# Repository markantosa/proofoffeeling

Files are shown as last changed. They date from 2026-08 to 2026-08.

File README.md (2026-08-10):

# Proof of Feeling

**Affective Core AC-7** — a speculative mechatronic artefact: an artificial
robotic heart that makes a humanoid AI's internal state visible through
pulse, motion, and light.

<p align="center">
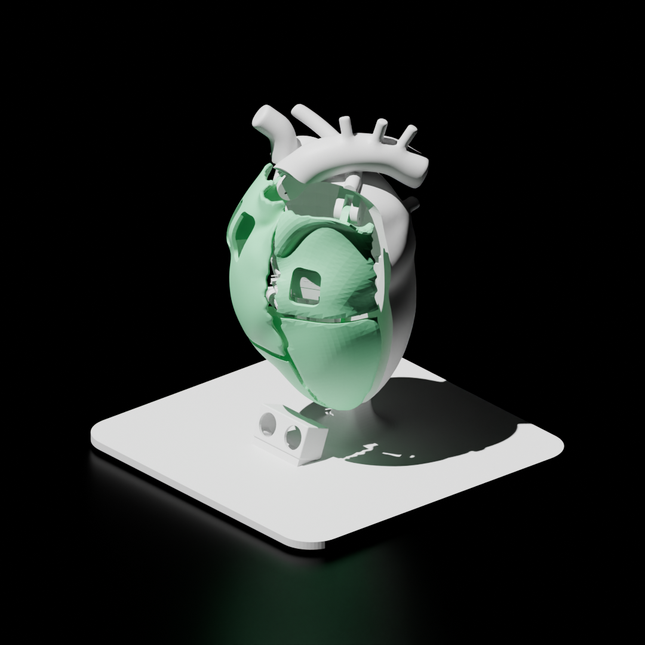
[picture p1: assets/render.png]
Proof of Feeling — rendered artificial heart with exposed PCB, mounted on its display stand
  
  <br><sub>Render made in Blender.</sub>
</p>

<p align="center">
  <a href="https://youtu.be/jkcCoCJa7ys">
    Proof of Feeling — short demo video (YouTube)
  </a>
  <br><sub>▶ Short demo — <a href="https://youtu.be/jkcCoCJa7ys">watch on YouTube</a></sub>
</p>

See [`docs/design-reference.md`](docs/design-reference.md) for the full
project concept and design brief.

## Repository Layout

```
.
├── docs/               Project-wide documentation
│   ├── design-reference.md          Project context/story + physical prototype
│   └── pcb-design-reference.md      KiCad 10 PCB design reference
├── firmware/           ESP32-C6-Supermini embedded firmware
│   ├── src/             Servo sweep, LED chase, proximity speed, eye animation, BLE telemetry
│   └── include/          Pin assignments, tunables, BLE UUIDs
├── dashboard/          BLE debug dashboard — ASCII face/sonar/heartbeat, Web Bluetooth (Chrome/Edge only)
├── electronics/        KiCad PCB project (single-layer milled board)
└── mechanical/         3D models — printable STL/3MF tracked via Git LFS; source .blend files not included yet
```

## Hardware Summary

* ESP32-C6-Supermini
* 2x SG92R micro servos, 5V (continuous 0–180° sweep, mirrored) — chosen over MG995 for size
* HC-SR04 ultrasonic sensor (proximity → continuous speed control)
* 1x momentary button, wired but currently unused by firmware
* 8x auxiliary LEDs, top-to-bottom chase ("pulse point" glow array)
* I2C OLED (SSD1306-class), 4-pin header — always-on blinking eye
* BLE telemetry (built-in radio) — feeds the debug dashboard, see below
* Custom single-layer milled PCB (KiCad, `electronics/`)
* Powered via 5V DC barrel plug

## Tools

* 3D modelling — Blender
* PCB design — KiCad
* Firmware — written with the aid of Claude

## Credits

* Heart geometry developed from [Realistic Human Heart](https://sketchfab.com/3d-models/realistic-human-heart-3f8072336ce94d18b3d0d055a1ece089) (Sketchfab)

<table>
  <tr>
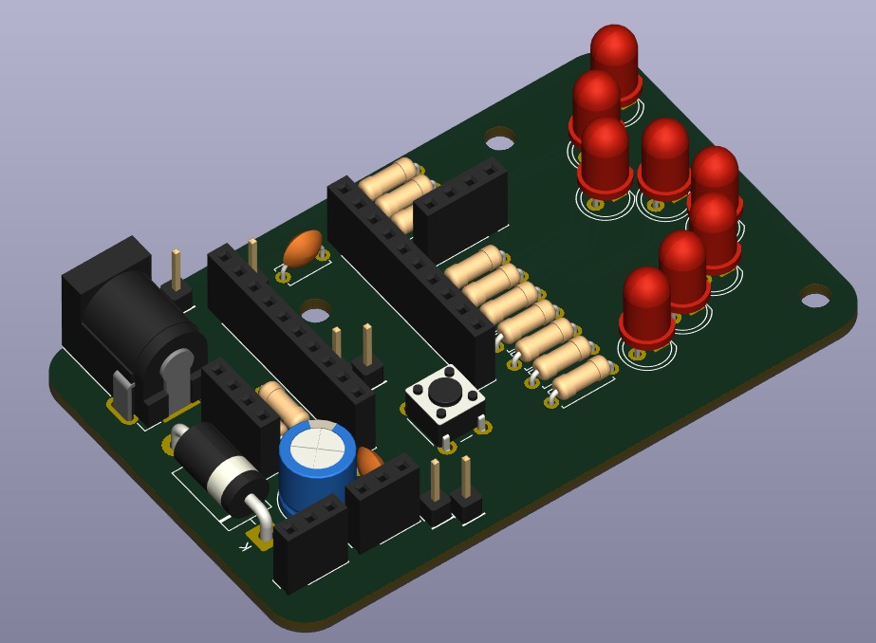
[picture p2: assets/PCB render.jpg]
3D render of the populated AC-7 main board
    <td align="center"><br><sub>Populated board render</sub></td>
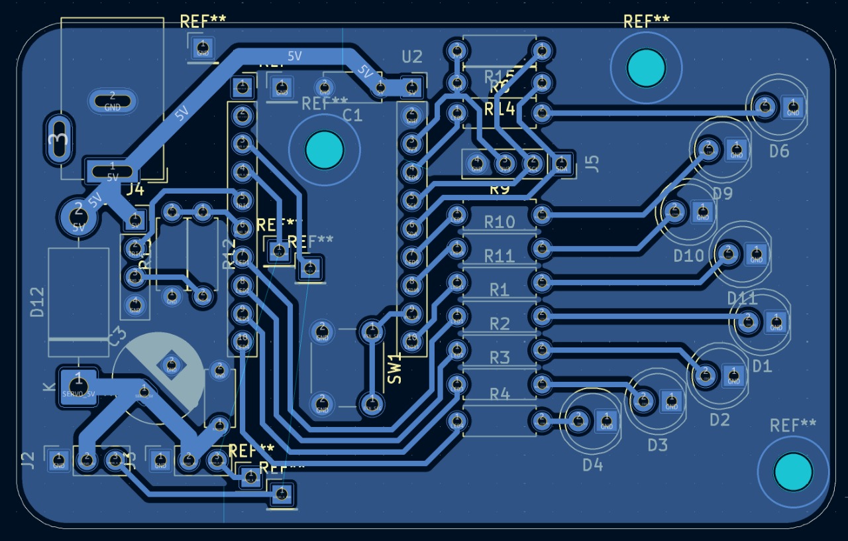
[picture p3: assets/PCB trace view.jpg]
AC-7 PCB routing — single-layer milled board, B.Cu traces
    <td align="center"><br><sub>B.Cu routing</sub></td>
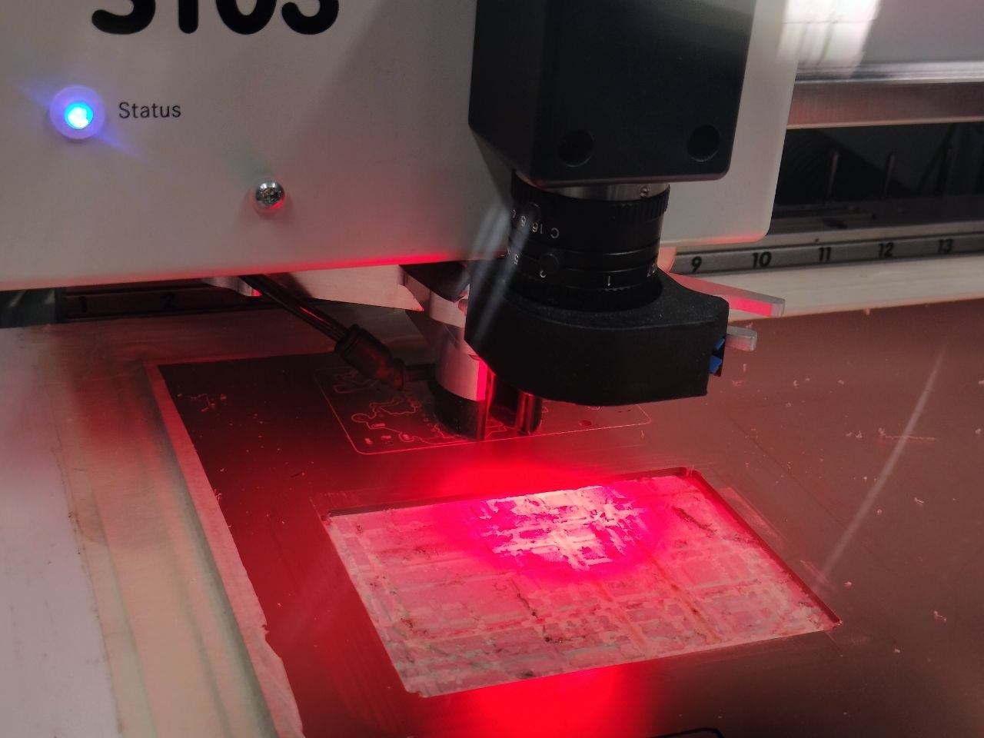
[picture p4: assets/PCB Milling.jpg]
AC-7 board mid-fabrication on a desktop CNC isolation mill
    <td align="center"><br><sub>Desktop CNC isolation milling</sub></td>
  </tr>
</table>

## Build

<table>
  <tr>
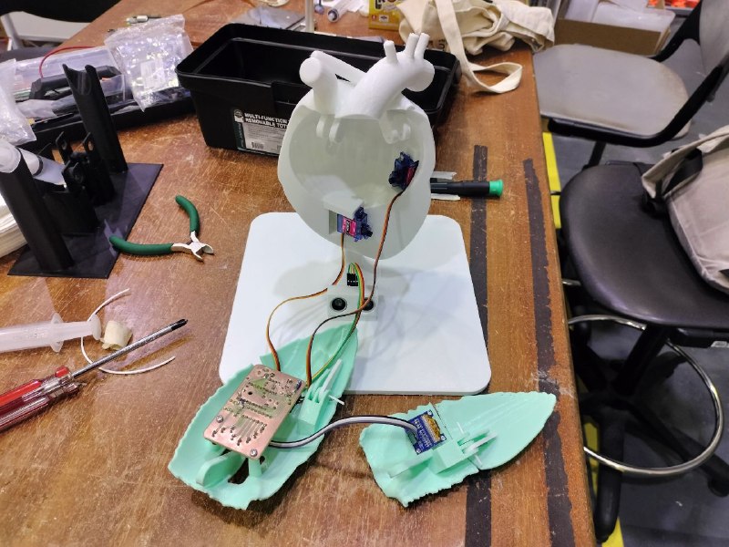
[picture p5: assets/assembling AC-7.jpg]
AC-7 mid-assembly — 3D-printed shell, PCB, and wiring on the workbench
    <td align="center"><br><sub>Assembly</sub></td>
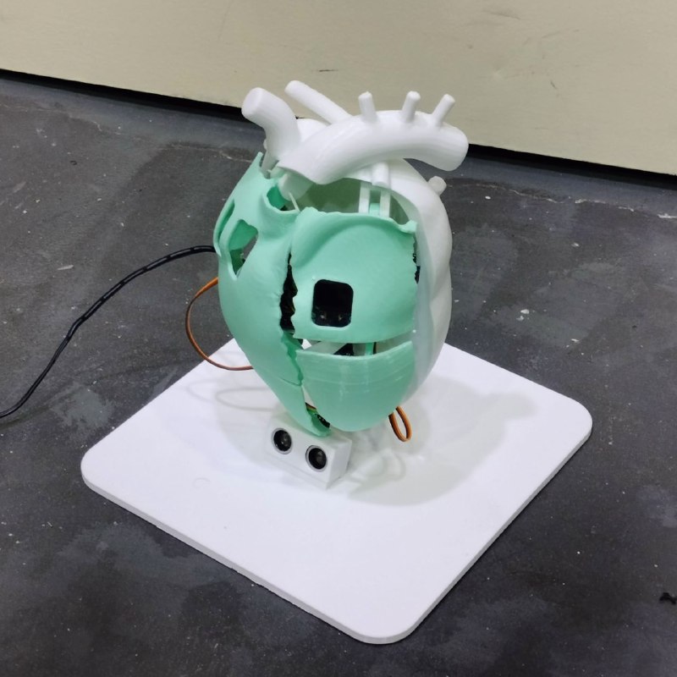
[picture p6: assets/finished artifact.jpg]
Finished AC-7 artefact — assembled artificial heart on its display stand
    <td align="center"><br><sub>Finished artefact</sub></td>
  </tr>
</table>

## Getting Started

* Project context, story, and what a viewer experiences: [`docs/design-reference.md`](docs/design-reference.md)
* Firmware build/flash instructions: [`firmware/README.md`](firmware/README.md)
* PCB design reference: [`docs/pcb-design-reference.md`](docs/pcb-design-reference.md)
* KiCad project: [`electronics/EPD 3D G6.kicad_pro`](electronics/EPD%203D%20G6.kicad_pro)
* BLE debug dashboard: [`dashboard/index.html`](dashboard/index.html) — open directly in Chrome or Edge (desktop/Android; Web Bluetooth isn't supported in Firefox/Safari), click **Connect**, pick "AC-7"

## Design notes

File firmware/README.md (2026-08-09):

# Affective Core AC-7 — Firmware

Embedded firmware and electronics documentation for **Proof of Feeling**, a
speculative mechatronic artefact. The Affective Core is an artificial
robotic heart that makes a humanoid AI's internal state visible through
pulse, motion, and light.

See [`../docs/design-reference.md`](../docs/design-reference.md) for the
full project concept and design brief.

## Hardware

* ESP32-C6-Supermini
* 2x SG92R micro servos, 5V (continuous 0–180° sweep, mirrored) — chosen over MG995 for size
* HC-SR04 ultrasonic sensor (proximity → continuous speed control)
* 5V DC barrel plug power input
* 1x momentary button — wired on the board (BTN_SIG/SW1), not read by
  the current firmware revision
* 8x auxiliary LEDs, chase top-to-bottom ("pulse point" glow array; 4
  PWM-faded, 4 on/off — see PCB doc for the LEDC channel budget)
* I2C OLED (SSD1306-class), 4-pin header — always-on eye animation,
  blinks at random intervals
* BLE telemetry (built-in radio, no extra hardware) — broadcasts
  distance + speed multiplier for the debug dashboard, see below
* Custom single-layer milled PCB — see
  [`../docs/pcb-design-reference.md`](../docs/pcb-design-reference.md)

## Repository Layout

This folder holds only the firmware; project-wide docs live in
[`../docs/`](../docs/) at the repo root, and the BLE debug dashboard
lives in [`../dashboard/`](../dashboard/).

```
.
├── platformio.ini          PlatformIO project config
├── include/
│   ├── config.h              Pin assignments and tunables
│   └── ble_telemetry.h       BLE service/characteristic declarations
└── src/
    ├── main.cpp               Servo sweep, LED chase, proximity speed, eye animation
    └── ble_telemetry.cpp      BLE GATT server — notifies distance + speed to the dashboard
```

## Build & Flash

Requires [PlatformIO](https://platformio.org/).

```
pio run              # build
pio run -t upload    # flash to ESP32-C6-Supermini
pio device monitor    # serial monitor, 115200 baud
```

## Behaviour (v3.0)

Continuous, proximity-driven — no discrete interaction-mode state
machine in this revision (an earlier v2.0 draft had one; it's gone):

| Element | Behaviour |
|---|---|
| Aux LEDs | Chase top-to-bottom in a wrapping pulse, continuously |
| Servos | Sweep 0°→180°→0° continuously, mirrored between the two |
| Speed | Both the LED chase and servo sweep speed up continuously as an object gets closer to the HC-SR04 — no discrete thresholds |
| OLED | Always displays an eye; blinks at random intervals, independent of the above |
| BLE | Notifies distance + speed multiplier (~10Hz) whenever a client is connected; harmless if nothing's listening |

See [`../docs/design-reference.md`](../docs/design-reference.md) §2 for
what this looks like from a viewer's side. The button (`BTN_SIG`) is
wired but currently unused — a candidate for a future interaction if one
gets designed.

## BLE Debug Dashboard

The firmware advertises as **AC-7** and exposes one GATT service (see
`include/ble_telemetry.h` for the UUIDs) that notifies an 8-byte struct
— `distanceCm` + `speedMultiplier` — at ~10Hz whenever a client is
connected. [`../dashboard/index.html`](../dashboard/index.html) is a
self-contained Web Bluetooth client for it: open it in Chrome or Edge
(desktop or Android — Web Bluetooth isn't supported in Firefox/Safari),
click **Connect**, and it renders:

* an ASCII face (sleeping / happy / stressed, thresholded on distance)
* an ASCII sonar sweep, pinging when something's in range
* a heartbeat thump + visual pulse, tempo-matched (not phase-locked) to
  the servo/LED speed

It's a debugging/demo tool, not part of the physical artefact — nothing
in `main.cpp`'s actual behaviour depends on whether a dashboard is
connected.

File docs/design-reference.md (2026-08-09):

# PROOF OF FEELING — DESIGN REFERENCE

**Affective Core AC-7** · Speculative Design / Mechatronic Artefact
Author: Vincent Santosa

---

## 1. Project Context & Story

*Proof of Feeling* is a speculative artefact from a near-future in which
humanoid robots have become convincing enough at simulating emotion that
human trust in them collapses. Regulators respond the way institutions
usually respond to a trust crisis: not by earning trust, but by
mandating proof of it. Every advanced humanoid must now contain an
**Affective Core** — a commercially manufactured robotic heart, sold
under the brand **AC-7** by *Companion Systems Inc.*, that makes a
robot's internal state externally visible through pulse, motion, and
light.

The heart does not sustain the robot. It sustains the *human's belief*
in the robot. That distinction is the entire design brief: this is not a
life-support organ, it's a trust interface wearing the shape of one —
performative rather than biological, engineered to be watched rather
than to function.

**Why this framing matters:** the project's actual subject isn't
robotics — it's what happens when trust is demanded on command instead
of earned. Manufactured proof of an inner state is not the same thing as
the inner state itself; it's a performance authored by whoever controls
the evidence. In the world of the AC-7, that's Companion Systems Inc. —
they design the pulse curves, choose the light behaviour, and program
every interaction mode in advance. The robot never gets to generate its
own evidence of feeling; the corporation does it on the robot's behalf,
the same way a regulator's compliance certificate stands in for the
thing it certifies. The heart is affirmative *within* the fiction (a
branded, reassuring, compliant product) while functioning as *critical*
design when offered to a viewer — it deliberately declines to answer
whether visible emotion equals genuine emotion, or who actually benefits
once a feeling becomes measurable and sellable.

This is also where the project is personal rather than purely
speculative. It's shaped by a Javanese sense that humility and quiet
consistency earn trust, while insistence on being seen and believed
usually signals the opposite — a relationship (or a system) that doesn't
trust itself enough to go unwatched. The AC-7 inverts that: it rewards
spectacle over restraint, and treats legibility as though it were the
same thing as trustworthiness. The project doesn't resolve that tension.
It's built to make a viewer sit inside it.

### The critical question

Not "can robots have feelings?" but:

**What happens when emotion becomes a manufactured interface?**

— and, closer to the surface: can empathy be engineered? Can trust be
designed? Is visible suffering required for moral consideration? Does
emotional transparency create understanding, or control? Who benefits
when emotion becomes measurable?

---

## 2. The User Side — Experiencing the Physical Prototype

The prototype is displayed as a **removed organ undergoing inspection**,
not a sculpture — the audience should feel they're looking at a real
industrial artefact, complete with product labels, serial numbers, and
inspection warnings ("Trust calibration required every 500 operating
hours."), sitting in a display cradle labelled `AFFECTIVE CORE · MODEL
AC-7 · PROPERTY OF COMPANION SYSTEMS INC.`

There is no button to press, no explicit "start" — the object is always
performing, the same way the fiction insists a real Affective Core would
be. What a viewer actually experiences:

* **It's always alive.** Two servo-driven anatomical structures move
  continuously — a slow, sweeping contraction/twist, mirrored between
  the two, so the object never looks static or off.
* **A pulse of light chases through the shell**, top to bottom, through
  a row of exposed "pulse point" LEDs behind the shell's translucent
  cutouts — read as bioelectric or vein-like activity rather than a
  simple blink.
* **It notices you.** An ultrasonic sensor detects when a viewer leans
  in. As they get closer, both the light pulse and the servo motion
  speed up — continuously, not as a discrete jump — so the object reads
  as *reacting to attention*, the same way a heart rate rises under
  scrutiny. Stepping back lets it slow back down.
* **It has an eye.** A small embedded screen shows a single eye that
  blinks at irregular, unscripted-feeling intervals — the one part of
  the object that behaves less like an instrument and more like it's
  looking back.
* **It carries the evidence of inspection**, not concealment: exposed
  copper traces styled after blood vessels and neural pathways, visible
  test points, fasteners, and calibration tags — synthetic and organic
  and corporate registers layered on top of each other on purpose.

The intended effect isn't "this looks alive" — it's closer to "this
looks like it was *designed to convince me* it's alive," and leaving
that gap visible is the point. A viewer who leans in and watches the
object visibly quicken in response is, in that moment, doing exactly
what the fiction's regulators designed the object for: deciding whether
to trust a machine by watching it perform. The project succeeds if that
prompts the discomfort of "would I actually trust something more because
it looks vulnerable to me?" — and fails if the only questions it
provokes are about the engineering (*what servo is that, does the
sensor work*) rather than the premise.

---

## Appendix: Physical Envelope

Target: 300mm × 250mm × 200mm · Maximum: 400mm × 400mm × 400mm (course
compliance).

For hardware specifics — servo/sensor/LED/display wiring, GPIO
assignments, firmware behaviour — see
[`pcb-design-reference.md`](pcb-design-reference.md) and
[`../firmware/README.md`](../firmware/README.md).

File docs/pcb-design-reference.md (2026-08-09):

# AFFECTIVE CORE AC-7 — PCB DESIGN REFERENCE

## Single-Layer Milled Board — KiCad 10

This revision matches the finalized schematic exactly (2 header rows for
the Supermini, 8 populated aux LEDs, I2C OLED header). Reference
designators follow the schematic's own numbering — see §5 for the full
scheme, in particular: **`D1`–`D11` are LEDs numbered to match their LED
net** (`D1`=`LED1` … `D11`=`LED11`), while **`D12` is the reverse-polarity
protection diode** — this is the opposite convention from earlier drafts
of this doc, so don't cross-reference old revisions.

---

# 1. BOARD OVERVIEW

Fabrication method: desktop CNC isolation milling (single-sided, copper on
bottom only — B.Cu). No vias, no plated through-holes, no top-side routing.
All components are through-hole (THT) so every connection can be made by a
hand-solderable pad reached from one side.

Because this is a single copper layer, every net that would otherwise need
to cross another net must either:

1. Route around it (preferred — and consistent with the "vein / neural
   pathway" decorative trace language in the main design doc), or
2. Jump it with a 0Ω resistor / bare wire link soldered on the top
   (component) side, treated in KiCad as a 2-pin "jumper" footprint.

Budget for 6–10 such jumpers on this board — the ESP32-C6-Supermini sits in
the middle of the layout with pins on both long edges, and the aux LED
array spans both rows, which forces several nets from one side to reach
components/headers on the other.

Board outline target: fits inside the heart shell cradle, roughly
70mm x 50mm. Confirm against the 3D-printed shell's internal mounting boss
positions before finalizing Edge.Cuts.

**Note on BLE**: the firmware broadcasts telemetry over Bluetooth LE (for
the debug dashboard — see `firmware/README.md`) using the Supermini
module's onboard radio/antenna. This needs no PCB component, footprint,
or net of its own — nothing on this board changes because of it.

---

# 2. KICAD 10 PROJECT SETUP

## 2.1 New Project

* File → New Project → "AC7_MainBoard"
* Symbol library: use default KiCad symbol libraries (Device, Connector,
  Switch) — no custom symbols required, see §5.
* Footprint library: default KiCad footprints (Resistor_THT, LED_THT,
  Connector_PinHeader_2.54mm, Connector_PinSocket_2.54mm,
  Button_Switch_THT) — no custom footprint needed, see §5.1.

## 2.2 Board Setup → Physical Stackup

* File → Board Setup → Board Editor Layers
* Untick every layer except: **F.Cu is NOT used** — untick it too.
  Keep only **B.Cu** enabled as the sole copper layer, plus Edge.Cuts,
  F.Silkscreen (for your own reference only — silkscreen will not be
  printed by the mill, but keeping it helps you read the layout on screen),
  and F.Fab/F.Courtyard if you want assembly reference.
* Rationale: all components are placed on the top (F) side and soldered
  through to pads that are milled on the bottom (B.Cu) side. Routing must
  therefore happen entirely on B.Cu.

## 2.3 Design Rules (Board Setup → Design Rules → Constraints)

Tuned for a typical 0.8–1.0mm end-mill / 0.1mm–0.2mm V-bit isolation job:

| Rule | Value |
|---|---|
| Minimum track width | 0.4mm (0.5mm preferred for power/servo nets) |
| Minimum clearance | 0.4mm |
| Minimum via | N/A — vias disabled, single layer |
| Minimum hole size | 0.8mm (drill), pad ≥ 1.7mm OD |
| Copper-to-edge clearance | 0.5mm |

Power nets (`+5V`, `SERVO_5V`, `GND`) should be widened to 0.8–1.0mm
manually where routing space allows. Both servos are SG92R micro servos
and draw stall currents in the ~650–750mA range each (~1.5A combined
worst case) — well within what a 0.4mm trace could handle at this
length, but the wider power-net width is cheap insurance and keeps
`SERVO_5V` consistent with the `+5V`/`GND` nets it shares a net class
with.

## 2.4 Net Classes

Create two net classes under Board Setup → Design Rules → Net Classes:

* **Default** — 0.4mm track / 0.4mm clearance — signal, sensor, LED, I2C,
  and `+3V3` nets.
* **Power** — 0.8mm track / 0.4mm clearance — assign nets `+5V`, `GND`,
  `SERVO_5V`.

## 2.5 Plotting for the Mill

File → Plot, or File → Fabrication Outputs:

* Export **B.Cu** and **Edge.Cuts** as Gerber (or SVG/DXF if your CAM chain
  — e.g. FlatCAM, pcb2gcode, Candle/GRBL — prefers vector formats).
* Export drill file via File → Fabrication Outputs → Drill Files
  (Excellon, one drill file, PTH+NPTH merged since nothing is plated).
* Because copper is on B.Cu only, **mirror the export** if your CAM
  workflow assumes you're milling the layer you're looking at from the top
  — check a test cut on scrap copper-clad before committing the real board.

---

# 3. POWER ARCHITECTURE

* **Input**: 5V DC via a 5V barrel plug (J1), external supply rated at
  least 5V/2A to cover two SG92R servos' combined stall current
  (~1.5A worst case) plus the Supermini and LED array headroom.
* **Two separate 5V nets** — this is the one subtlety worth calling out
  clearly, since it's easy to assume everything downstream of J1 is
  protected the same way:
  * **`+5V`** — raw, straight off J1, *before* the protection diode.
    Feeds the Supermini's own 5V/VIN pin (`U2` pin 1) and the HC-SR04
    (`J4` pin 1) directly.
  * **`SERVO_5V`** — *after* D12 (the reverse-polarity diode), feeds only
    the two servo headers (J2/J3). Only the servo rail is diode-protected
    in this design; the MCU and ultrasonic sensor are not. If reverse
    polarity protection for the whole board matters to you, that's worth
    revisiting, but as drawn, only the high-current/most-exposed servo
    path gets it.
* **ESP32-C6 logic**: 3.3V, generated on-module by the Supermini's onboard
  regulator. The one net distributed off that regulator on this PCB is
  **`+3V3`** (from `U2` pin 3), which powers the I2C OLED (J5) and its
  pull-up resistors (R14/R15). An SSD1306-class OLED draws well under the
  regulator's spare headroom (typically <20mA), so no separate 3.3V
  regulation is needed.
* **HC-SR04**: runs on raw `+5V`. Its ECHO output swings to 5V and MUST be
  divided down before reaching the C6's 3.3V-only GPIO (R12/R13 divider,
  see §4). TRIG is driven by a 3.3V GPIO, which the HC-SR04 reliably reads
  as logic HIGH — no level shifting needed on TRIG.
* **Reverse-polarity protection**: D12, a Schottky diode (e.g. SS24,
  rated ≥2A — comfortable margin over the two SG92R servos' ~1.5A
  combined stall current) in series between `+5V` and `SERVO_5V`. Costs
  ~0.3V drop on the servo rail only.

---

# 4. NET LIST

| Net name | Description | Connects |
|---|---|---|
| `+5V` | Raw 5V input rail (pre-diode) | J1.1, D12 anode, U2.1 (Supermini VIN), J4.1 (HC-SR04 VCC), C1 |
| `SERVO_5V` | Post-diode 5V, servos only | D12 cathode, J2.2, J3.2, C2, C3 |
| `GND` | Common ground | J1.2, U2.2, J2.1, J3.1, J4.4, SW1 (leg 2), J5.4, R13 (divider low side), all LED cathodes (D1–D11) |
| `SERVO_A_PWM`  | Servo A signal | U1.3 → J2.3 |
| `SERVO_B_PWM`  | Servo B signal | U1.4 → J3.3 |
| `TRIG` | Ultrasonic trigger | U1.5 → J4.2 |
| `ECHO_5V` | Raw 5V echo output from HC-SR04 | J4.3 → R12 |
| `ECHO_3V3` | Divided echo signal into MCU | R12/R13 junction → U1.6 |
| `BTN_SIG` | Button input | U2.9 → SW1 (leg 1) |
| `LED1`…`LED4`  | Aux LEDs — PWM-faded (4 of 6 free LEDC channels; servos use the other 2) | U1.7/8/9/10 → R1…R4 → D1…D4 anode |
| `LED6` | Aux LED — on/off | U2.4 → R6 → D6 anode |
| `LED9` | Aux LED — on/off | U2.7 → R9 → D9 anode |
| `LED10` | Aux LED — on/off | U2.8 → R10 → D10 anode |
| `LED11` | Aux LED — on/off. Shares GP8 with the onboard WS2812 DIN (see §5.2) | U2.10 → R11 → D11 anode |
| `+3V3` | 3.3V, tapped from the Supermini's onboard regulator | U2.3 → J5.3, R14/R15 pull-ups |
| `I2C_SDA` | I2C data, OLED | U2.6 → J5.1, pull-up to `+3V3` |
| `I2C_SCL` | I2C clock, OLED | U2.5 → J5.2, pull-up to `+3V3` |

**LED numbering has gaps by design** — `LED5`, `LED7`, `LED8` don't exist
on this board. `LED5` (GP12) was dropped entirely; `LED7`/`LED8` (GP19/
GP18) were reassigned to `I2C_SCL`/`I2C_SDA` instead. This is expected,
not a missing-component error — see §5.2 for the full pin-by-pin
accounting.

**LED physical position, top → bottom on the shell** (this is the order
the firmware chases through — see `include/config.h` `PIN_LED_AUX[]`):

```
LED6 → LED9 → LED10 → LED11 → LED1 → LED2 → LED3 → LED4
```

| Position (top→bottom) | LED | GPIO | Resistor | Diode | Drive |
|---|---|---|---|---|---|
| 1 | LED6  | 20 | R6 | D6 | on/off |
| 2 | LED9  | 15 | R9 | D9 | on/off |
| 3 | LED10 | 14 | R10 | D10 | on/off |
| 4 | LED11 | 8 (also WS2812 DIN) | R11 | D11 | on/off |
| 5 | LED1  | 4 | R1 | D1 | PWM (fade) |
| 6 | LED2  | 5 | R2 | D2 | PWM (fade) |
| 7 | LED3  | 6 | R3 | D3 | PWM (fade) |
| 8 | LED4  | 7 | R4 | D4 | PWM (fade) |

⚠️ **LEDC channel budget**: the ESP32-C6 has 6 total LEDC PWM channels.
The 2 servos consume 2, leaving 4 free — that's why only LED1–LED4 fade;
the rest are driven as plain digitalWrite on/off in firmware
(`writeAuxLed()` in `main.cpp`), not PWM-capable, so no LEDC channel is
needed for them. Physically, the 4 fading LEDs are the second half of the
chase (positions 5–8), not the first — the pulse animation still reads
fine either way since it's a continuous glow sweep, not a fixed brightness
step.

---

# 5. REFERENCE DESIGNATORS, SYMBOLS & FOOTPRINTS

| Ref | Part | KiCad Symbol (library:name) | KiCad Footprint | Notes |
|-----|---|---|---|---|
| U1  | ESP32-C6-Supermini, left pin row (plugs into sockets — see §5.1) | `Connector_Generic:Conn_01x10` — no stock symbol matches the Supermini's specific pinout, label each pin manually | `Connector_PinSocket_2.54mm:PinSocket_1x10_P2.54mm_Vertical` — stock footprint, no custom footprint needed | Only 10 of the row's 12 physical pins are used (pins 1–2 are TX/RX, unconnected); pins 11–12 (GP23/GP22) aren't wired to anything |
| U2  | ESP32-C6-Supermini, right pin row (plugs into sockets — see §5.1) | `Connector_Generic:Conn_01x10` — same caveat as U1 | `Connector_PinSocket_2.54mm:PinSocket_1x10_P2.54mm_Vertical` | Only 10 of the row's 14 physical pins are used — pin 1 (BAT) and pins 12–14 (GP12/GP13/GP21) aren't wired to anything. See §5.2 for the full physical-to-schematic pin mapping |
| J1  | Power input, 5V DC barrel plug | `Connector:Barrel_Jack` | `Connector_BarrelJack:BarrelJack_Horizontal` | Rate for ≥3A; match plug OD/ID to the chosen 5V supply |
| D12 | Schottky diode, reverse-polarity protection (`SERVO_5V` only) | `Diode:D_Schottky` (generic Schottky symbol — set Value field to `SS24`; there is no part-specific `SS24` symbol in the stock library) | `Diode_THT:D_DO-201AD_P15.24mm_Horizontal` | Rated ≥2A — comfortable margin over SG92R stall current |
| J2  | Servo A header (3-pin: GND/SERVO_5V/PWM) | `Connector_Generic:Conn_01x03` | `Connector_PinHeader_2.54mm:PinHeader_1x03_P2.54mm_Vertical` | Pin order per schematic: GND, SERVO_5V, SERVO_A_PWM — confirm against your SG92R plug wire colors before crimping |
| J3  | Servo B header (3-pin) | `Connector_Generic:Conn_01x03` | `Connector_PinHeader_2.54mm:PinHeader_1x03_P2.54mm_Vertical` | Same pin order as J2 |
| J4  | HC-SR04 header (4-pin: 5V/TRIG/ECHO_5V/GND) | `Connector_Generic:Conn_01x04` | `Connector_PinHeader_2.54mm:PinHeader_1x04_P2.54mm_Vertical` | Order to match sensor module silkscreen |
| J5  | I2C OLED header (4-pin: SDA/SCL/3V3/GND) | `Connector_Generic:Conn_01x04` | `Connector_PinHeader_2.54mm:PinHeader_1x04_P2.54mm_Vertical` | Pin order is SDA, SCL, 3V3, GND per schematic — this does **not** match every OLED breakout's silkscreen order, double-check before wiring |
| SW1 | Momentary tactile button | `Switch:SW_Push` | `Button_Switch_THT:SW_PUSH_6mm` | Leg 1 → `BTN_SIG`, leg 2 → `GND`. Wired on the board but not read by the current firmware revision |
| D1–D4, D6, D9–D11 | Aux LEDs (8x populated, 3mm or 5mm THT) — designator matches LED net number, **not** sequential (D5/D7/D8 don't exist) | `Device:LED` | `LED_THT:LED_D5.0mm` (or `LED_D3.0mm`) | Route to physical positions on the shell per the top→bottom chase order in §4 |
| R1–R4, R6, R9–R11 | LED current-limit resistors (330Ω for 5mm red/amber LEDs at 3.3V/5V logic; recalc per LED Vf/If) — same gapped numbering as the diodes | `Device:R` | `Resistor_THT:R_Axial_DIN0207_L6.3mm_D2.5mm_P10.16mm_Horizontal` | One per LED, in series with GPIO |
| R12 | Echo divider, top (5V side) | `Device:R` — 1kΩ | `Resistor_THT:R_Axial_DIN0207_L6.3mm_D2.5mm_P10.16mm_Horizontal` | R12/R13 form a 2:1 divider: 5V × (R13/(R12+R13)) ≈ 3.3V |
| R13 | Echo divider, bottom (GND side) | `Device:R` — 2kΩ | `Resistor_THT:R_Axial_DIN0207_L6.3mm_D2.5mm_P10.16mm_Horizontal` | Junction of R12/R13 → `ECHO_3V3` → U1.6 |
| R14, R15 | I2C pull-ups — 4.7kΩ, one on SDA one on SCL | `Device:R` | `Resistor_THT:R_Axial_DIN0207_L6.3mm_D2.5mm_P10.16mm_Horizontal` | Omit both if your OLED breakout already has onboard SDA/SCL pull-ups (most SSD1306 modules do — check before populating). **Verify which of R14/R15 lands on SDA vs SCL against your schematic file** — both are 4.7kΩ so a swap has no functional effect, but keep your silkscreen/BOM consistent |
| C1  | Decoupling on `+5V`, near U2 pin 1 (Supermini VIN) | `Device:C` — 100nF | `Capacitor_THT:C_Disc_D3.0mm_W2.5mm_P2.50mm` | |
| C2  | Decoupling on `SERVO_5V`, near J2/J3 | `Device:C` — 100nF | `Capacitor_THT:C_Disc_D3.0mm_W2.5mm_P2.50mm` | |
| C3  | Bulk decoupling on `SERVO_5V`, near J2/J3 | `Device:C_Polarized` — 220–470µF, 16V | `Capacitor_THT:CP_Radial_D8.0mm_P3.50mm` | Damps servo current-draw transients so they don't reset the C6 |

## 5.1 ESP32-C6-Supermini — Socketed Mounting (Header Sockets)

The module plugs into header sockets rather than being soldered or laid out
as a custom module footprint. This means the PCB side only needs two stock
2.54mm pin-socket footprints — no custom `.kicad_mod` required:

* Solder two **female 2.54mm pin header sockets** to the PCB, spaced
  ~17.8mm apart center-to-center (verify against the actual module you
  have; Supermini clones vary between vendors even when visually similar
  — measure before milling).
* The physical header rows are 12 pins (left) and 14 pins (right), but
  this schematic only wires up 10 pins on each side — see §5.2 for
  exactly which physical pins are used vs left unconnected. You can
  either socket only the pins you need, or socket the full row and leave
  the unused pads unpopulated/no-connect — either works.
* PCB footprint: stock `Connector_PinSocket_2.54mm:PinSocket_1x10_P2.54mm_Vertical`
  for the 10 populated positions on each row (or size to the full
  physical row length if you'd rather socket the whole thing).
* Schematic symbol for each row: stock `Connector_Generic:Conn_01x10`
  (U1, U2). There is no ESP32-C6-Supermini symbol in the stock KiCad
  library and none is needed for a socketed connector — just rename each
  pin in the symbol properties/net labels to match the module's actual
  silkscreen, rather than modeling a dedicated MCU symbol.
* The module itself needs no PCB footprint at all — it's a separate,
  removable part that carries its own male header pins and simply plugs
  into the sockets. This is also what makes it swappable if a module is
  damaged during the build.

Before laying out nets to U1/U2, confirm your physical module's actual
pin labels with a multimeter continuity check against its
datasheet/silkscreen — clone boards from different vendors are not
pin-identical.

## 5.2 Pinout Quick Reference

Every physical pin on both header rows, its net on this board (from §4),
and what it's used for. `—` means the pin is present on the module but
not wired to anything on this schematic.

**U1 — left row (physical 12 pins, top → bottom; only pins 1–10 wired)**

| Pin | Module Label | Net | Usage |
|-----|---|---|---|
| 1 | TX | — | Unused |
| 2 | RX | — | Unused |
| 3 | GP0 | `SERVO_A_PWM` | Servo A (J2) |
| 4 | GP1 | `SERVO_B_PWM` | Servo B (J3) |
| 5 | GP2 | `TRIG` | Ultrasonic trigger (J4) |
| 6 | GP3 | `ECHO_3V3` | Ultrasonic echo, divided (J4 via R12/R13) |
| 7 | GP4 | `LED1` | Aux LED D1 (R1) — PWM |
| 8 | GP5 | `LED2` | Aux LED D2 (R2) — PWM |
| 9 | GP6 | `LED3` | Aux LED D3 (R3) — PWM |
| 10  | GP7 | `LED4` | Aux LED D4 (R4) — PWM |
| 11  | GP23 | — | Unused, not on schematic |
| 12  | GP22 | — | Unused, not on schematic |

**U2 — right row (physical 14 pins, top → bottom; only pins 2–11 wired)**

| Pin | Module Label | Net | Usage |
|-----|---|---|---|
| 1 | BAT | — | Unused, not on schematic (battery input; board is powered via J1) |
| 2 | 5V | `+5V` | Raw 5V in from J1 (pre-diode, powers the module directly) |
| 3 | GND | `GND` | Common ground |
| 4 | 3V3(OUT) | `+3V3` | OLED VCC (J5) + I2C pull-ups (R14/R15) |
| 5 | GP20 | `LED6` | Aux LED D6 (R6) — on/off |
| 6 | GP19 | `I2C_SCL` | OLED I2C clock (J5) |
| 7 | GP18 | `I2C_SDA` | OLED I2C data (J5) |
| 8 | GP15 | `LED9` | Aux LED D9 (R9) — on/off |
| 9 | GP14 | `LED10` | Aux LED D10 (R10) — on/off |
| 10  | GP9 (BOOT) | `BTN_SIG` | Momentary button (SW1) |
| 11  | GP8 | `LED11` | Aux LED D11 (R11) — on/off. Also drives the onboard WS2812 RGB LED's `DIN`; an external LED here will flicker with whatever pattern is sent, and the onboard WS2812 reacts to the same signal — this pin is doing double duty |
| 12  | GP12 | — | Unused, not on schematic |
| 13  | GP13 | — | Unused, not on schematic. No status LED in this design revision |
| 14  | GP21 | — | Unused, not on schematic |

**Top edge** (onboard buttons, not header pins): `BOOT`, `RST` — no net,
no PCB connection.

---

# 6. SCHEMATIC SHEET STRUCTURE

Suggested schematic hierarchy (single flat sheet is fine at this
component count, but grouping helps readability):

1. **Power** — J1, D12, C1, C2, C3, `+5V`/`SERVO_5V`/`GND` labels
2. **MCU** — U1, U2 (socket rows) with all net labels flying to the rest
   of the sheet (avoids drawing every wire across the whole page)
3. **Actuators** — J2, J3 (servo headers)
4. **Sensors** — J4 (ultrasonic), R12/R13 divider, SW1 (button)
5. **LED Array** — D1–D4/D6/D9–D11, R1–R4/R6/R9–R11 (note which are PWM
   vs on/off per §4)
6. **Display** — J5 (OLED header), R14/R15 (I2C pull-ups), `+3V3` label

Use hierarchical labels or global labels (not raw wires) for `+5V`,
`SERVO_5V`, `+3V3`, `GND`, `SERVO_A_PWM`, `SERVO_B_PWM`, `TRIG`,
`ECHO_3V3`, `BTN_SIG`, `LED1`–`LED11` (gapped), `I2C_SDA`, `I2C_SCL` so
ERC can check net connectivity without a tangle of crossing wires on the
schematic canvas.

---

# 7. PHYSICAL LAYOUT & WIRING GUIDE

## 7.1 Placement Strategy

1. Place U1/U2 (Supermini header sockets) roughly centered, oriented so
   U1's GP0–GP3 (servos/ultrasonic) face one edge and U2's GP20/GP19/
   GP18/GP15/GP14/GP9/GP8 face the opposite or adjacent edge — minimizes
   trace length and crossings.
2. Place J2/J3 (servo headers) along the edge nearest U1's GP0/GP1.
3. Place J4 (ultrasonic header) along the edge nearest U1's GP2/GP3, with
   R12/R13 directly adjacent to it (keep the divider physically close to
   the header, not close to the MCU, so `ECHO_5V` stays short and only
   the already-safe `ECHO_3V3` net runs the longer distance to U1).
4. Place J1 (power in) + D12 + C1/C2/C3 at a board edge, away from signal
   headers, to keep the high-current power entry point isolated.
5. Distribute D1–D4/D6/D9–D11 + their resistors around the board
   perimeter facing outward toward the shell's translucent "pulse point"
   cutouts, **in physical top-to-bottom order matching the chase
   animation**: LED6 → LED9 → LED10 → LED11 → LED1 → LED2 → LED3 → LED4
   (see §4). This isn't just cosmetic — the firmware assumes this order
   for the sweeping pulse effect to read as a single wave moving in one
   direction, so keep the physical placement sequential even though the
   nets themselves don't need to route in that order. LED1–LED4 come off
   U1 (left row) while LED6/9/10/11 come off U2 (right row), so this
   array spans both sides of the MCU — expect more jumpers than a
   smaller LED count would need (see §7.3).
6. Place SW1 wherever the shell's physical button cutout requires —
   route `BTN_SIG` to it last, since it's low-priority/low-current (and
   currently unused by firmware).
7. Place J5 (OLED header) + R14/R15 (I2C pull-ups) close together near
   U2's GP19/GP18/3V3(OUT) pins — I2C is not particularly sensitive on a
   slow bus like this, but keeping the pull-ups near the header (not near
   the MCU) keeps the trace length that carries the "raw" bus short and
   off the shared perimeter routing used by the decorative LEDs.

## 7.2 Routing Order (single layer — do the constrained nets first)

1. **GND** — route as wide as possible first; consider a partial ground
   pour (Edit → Fill Zone) on B.Cu in open areas instead of a discrete
   trace, since GND has the most connections. A zone still counts as
   "single layer" — it's just copper fill on B.Cu, no via needed as long
   as every GND pad is a THT pin planted directly into that fill.
2. **`+5V` / `SERVO_5V`** — route next at 0.8–1.0mm width. `+5V` runs
   shortest-path from J1 to D12/U2/J4; `SERVO_5V` runs shortest-path from
   D12 to J2/J3.
3. **`SERVO_A_PWM`, `SERVO_B_PWM`, `TRIG`, `ECHO_3V3`, `BTN_SIG`,
   `I2C_SDA`, `I2C_SCL`** — signal nets, 0.4mm, route with generous
   curves (arcs, not 90° corners — both looks organic and mills more
   reliably than sharp interior corners at small bit diameters). `+3V3`
   can route at 0.4mm too — the OLED's current draw is trivial, it
   doesn't need the 0.8mm power-net width.
4. **`LED1`–`LED11`** (gapped) — route last, since they're the most
   flexible (non-critical, low current, purely decorative routing is
   encouraged).

## 7.3 Handling Crossovers (no second layer available)

Where two nets must cross and cannot be routed around each other:

* Prefer detouring one net around the conflict — with a moderate net
  count and generous board area this is usually possible.
* If unavoidable, insert a 2-pin **jumper footprint**
  (`Jumper:SolderJumper-2_P1.3mm_Bridged` or a plain 0Ω axial resistor
  footprint used as a wire link) in the net that needs to hop over. The
  jumper's two pads sit on either side of the obstruction; a bare wire is
  soldered across the top (component) side, physically bridging over the
  milled trace it's crossing without touching it.
* Document each jumper's location on the silkscreen/F.Fab reference layer
  even though it won't mill, so hand-assembly can find it easily.

## 7.4 Test Points

Consistent with the "visible test points" visual language in the main
design doc: add a handful of small unconnected-pad test points
(`TestPoint:TestPoint_Pad_D1.0mm`) on `+5V`, `GND`, `SERVO_A_PWM`, and
`ECHO_3V3` — functionally optional, but they read as an inspected
industrial artefact under the exhibition lighting and double as real
probe points for bring-up debugging.

---

# 8. BRING-UP / ASSEMBLY CHECKLIST

1. Mill B.Cu + drill, deburr, and continuity-check every net against this
   table with a multimeter **before** populating any parts.
2. Solder passives first (R1–R4, R6, R9–R15, C1–C3), then headers/sockets
   (J1–J5, U1/U2 female sockets), then SW1, then D1–D4/D6/D9–D12 last
   (easiest to damage with heat / easiest to get polarity backwards —
   check flat edge = cathode against the `GND`-side pad before
   soldering).
3. Insert the Supermini into its U1/U2 sockets. Power J1 at 5V with
   servos/HC-SR04 disconnected first; confirm the Supermini boots
   (check serial monitor at 115200 baud for the boot banner in
   `src/main.cpp`) before attaching J2/J3/J4.
4. Attach HC-SR04, verify `ECHO_3V3` never exceeds 3.3V at the R12/R13
   junction with a multimeter before trusting it against GPIO3.
5. Attach servos one at a time, confirm `SERVO_5V` rail voltage doesn't
   sag below ~4.5V under load (add/verify C3 if it does). SG92R stall
   current is modest, but still verify the 5V barrel-plug supply and
   J1/D12 are comfortably rated for both servos stalling simultaneously.
6. Attach the OLED to J5, verify `+3V3` measures 3.0–3.3V at J5.3 before
   connecting the display, then power up and confirm the eye animation
   appears. If nothing shows, check R14/R15 are actually populated (or
   that the breakout's onboard pull-ups are present) before assuming the
   display itself is faulty, and confirm J5's SDA/SCL/3V3/GND order
   actually matches your specific OLED breakout's silkscreen — cheap
   breakouts are not consistent about pin order.
7. With everything attached, verify the LED chase visibly sweeps
   top-to-bottom in the order given in §4/§7.1, and that bringing an
   object closer to the HC-SR04 visibly speeds up both the LED chase and
   the servo sweep. If the chase runs in the wrong direction or looks
   scrambled, check `PIN_LED_AUX[]` in `include/config.h` against the
   physical LED placement on the shell.

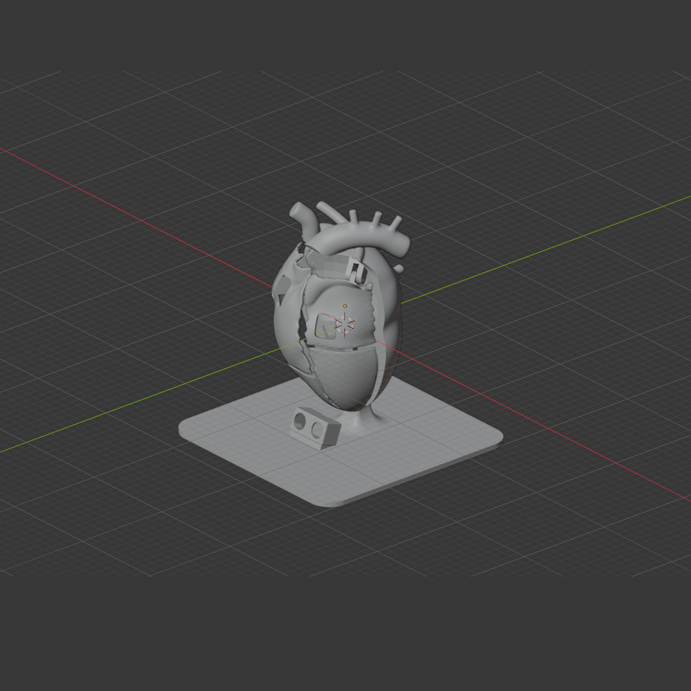
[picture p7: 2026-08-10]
assets/blender viewport.png

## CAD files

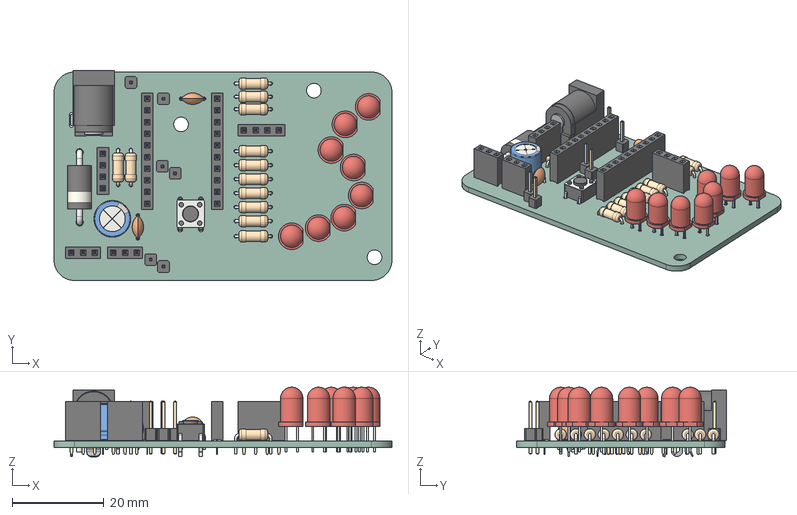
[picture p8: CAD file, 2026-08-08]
electronics/PoF PCB.step
73.7 x 45.8 x 15.2 mm
LED_D5.0mm x 8
C_Disc_D50mm_W25mm_P500mm x 2
R_Axial_DIN0207_L63mm_D25mm_P762mm_Horizontal x 12
BarrelJack_GCT_DCJ200-10-A_Horizontal
PinHeader_1x01_P254mm_Vertical x 6
D_DO-201AD_P15.24mm_Horizontal
PinSocket_1x10_P2.54mm_Vertical x 2
SW_PUSH_6mm
PinSocket_1x04_P2.54mm_Vertical x 2
PinSocket_1x03_P2.54mm_Vertical x 2
CP_Radial_D80mm_P350mm
EPD 3D G6_PCB

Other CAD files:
mechanical/printables/3mf files/back.3mf
mechanical/printables/servo arm.stl
mechanical/printables/3mf files/cloves.3mf
mechanical/printables/top left.stl
mechanical/printables/3mf files/base.3mf
mechanical/printables/bottom right.stl
mechanical/printables/bottom left.stl
mechanical/printables/top right.stl
mechanical/printables/back.stl
mechanical/printables/base.stl

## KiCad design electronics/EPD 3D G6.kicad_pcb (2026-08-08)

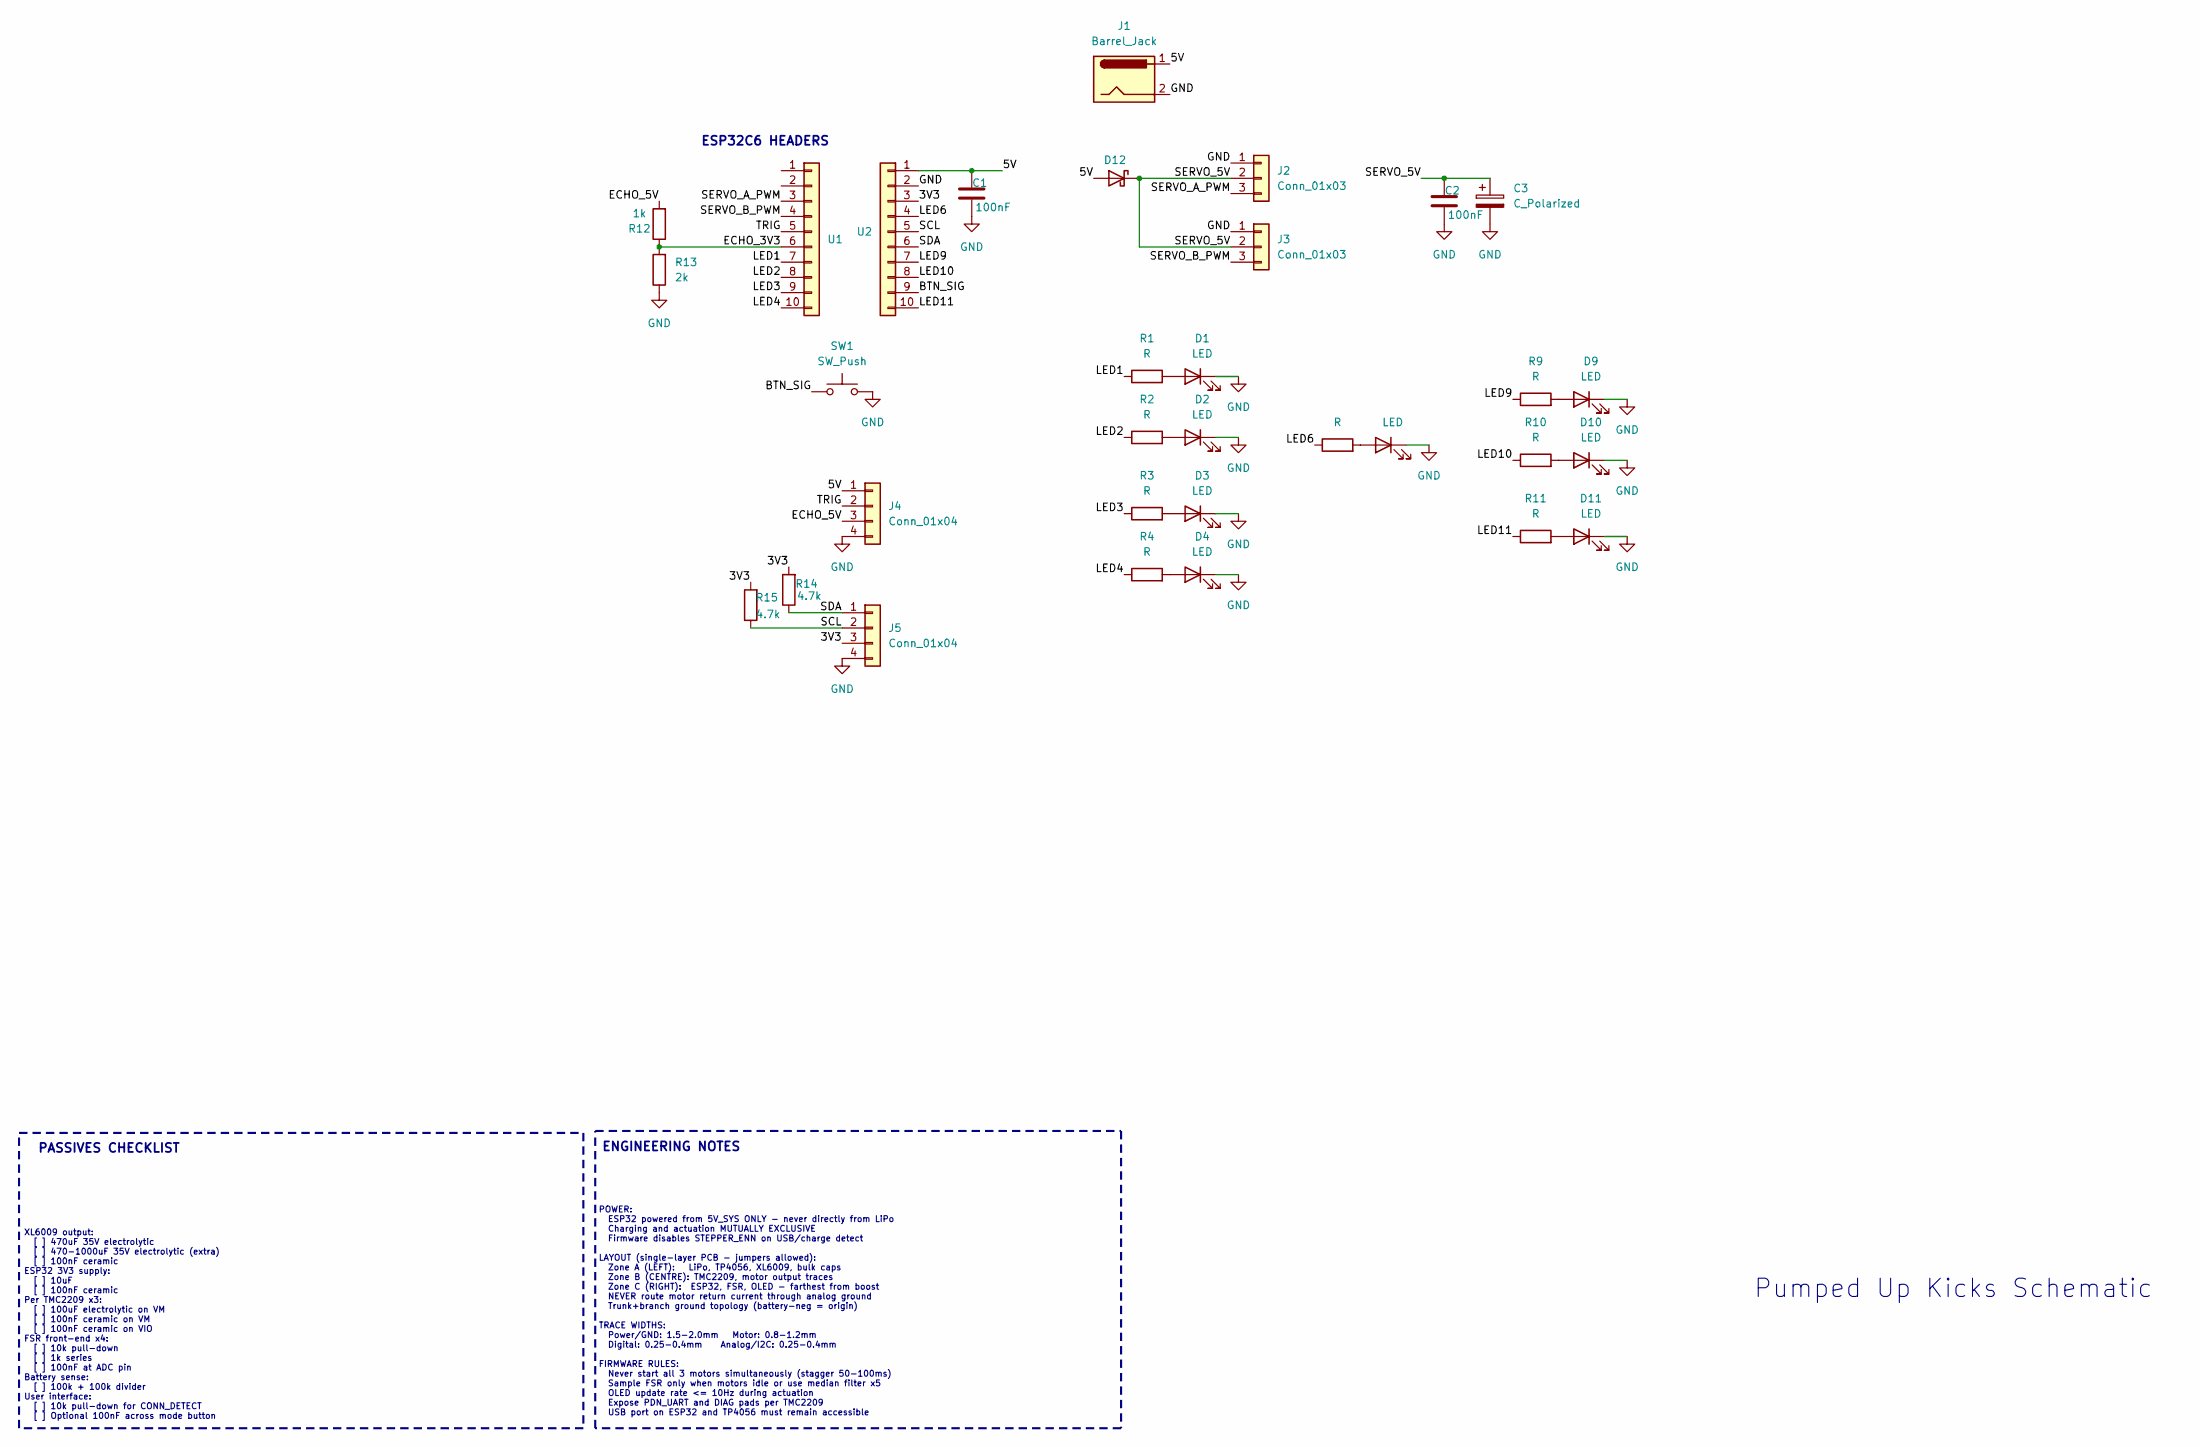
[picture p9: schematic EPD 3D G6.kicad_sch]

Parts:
C1, C2: 100nF; C_Disc_D5.0mm_W2.5mm_P5.00mm
C3: C_Polarized; CP_Radial_D8.0mm_P3.50mm
D1, D2, D3, D4, D6, D9, D10, D11: LED; LED_D5.0mm
D12: D_Schottky; D_DO-201AD_P15.24mm_Horizontal
J1: Barrel_Jack; BarrelJack_GCT_DCJ200-10-A_Horizontal
J2, J3: Conn_01x03; PinSocket_1x03_P2.54mm_Vertical
J4, J5: Conn_01x04; PinSocket_1x04_P2.54mm_Vertical
R1, R2, R3, R4, R6, R9, R10, R11: R; R_Axial_DIN0207_L6.3mm_D2.5mm_P7.62mm_Horizontal
R12: 1k; R_Axial_DIN0207_L6.3mm_D2.5mm_P7.62mm_Horizontal
R13: 2k; R_Axial_DIN0207_L6.3mm_D2.5mm_P7.62mm_Horizontal
R14, R15: 4.7k; R_Axial_DIN0207_L6.3mm_D2.5mm_P7.62mm_Horizontal
SW1: SW_Push; SW_PUSH_6mm
U1, U2: Conn_01x10; PinSocket_1x10_P2.54mm_Vertical

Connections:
/3V3: J5.3, R14.2, R15.2, U2.3
/5V: C1.1, D12.2 (A), J1.1, J4.1, U2.1
/BTN_SIG: SW1.1, U2.9
/ECHO_3V3: R12.1, R13.2, U1.6
/ECHO_5V: J4.3, R12.2
/LED1: R1.1, U1.7
/LED2: R2.1, U1.8
/LED3: R3.1, U1.9
/LED4: R4.1, U1.10
/LED6: R6.1, U2.4
/LED9: R9.1, U2.7
/LED10: R10.1, U2.8
/LED11: R11.1, U2.10
/SCL: J5.2, R15.1, U2.5
/SDA: J5.1, R14.1, U2.6
/SERVO_5V: C2.1, C3.1, D12.1 (K), J2.2, J3.2
/SERVO_A_PWM: J2.3, U1.3
/SERVO_B_PWM: J3.3, U1.4
/TRIG: J4.2, U1.5
GND: C1.2, C2.2, C3.2, D1.1 (K), D2.1 (K), D3.1 (K), D4.1 (K), D6.1 (K), D9.1 (K), D10.1 (K), D11.1 (K), J1.2, J2.1, J3.1, J4.4, J5.4, R13.1, SW1.2, U2.2
unnamed: D1.2 (A), R1.2
unnamed: D2.2 (A), R2.2
unnamed: D3.2 (A), R3.2
unnamed: D4.2 (A), R4.2
unnamed: D6.2 (A), R6.2
unnamed: D9.2 (A), R9.2
unnamed: D10.2 (A), R10.2
unnamed: D11.2 (A), R11.2

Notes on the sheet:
Pumped Up Kicks Schematic
PASSIVES CHECKLIST
ESP32C6 HEADERS
XL6009 output: [ ] 470uF 35V electrolytic [ ] 470-1000uF 35V electrolytic (extra) [ ] 100nF ceramic ESP32 3V3 supply: [ ] 10uF [ ] 100nF ceramic Per TMC2209 x3: [ ] 100uF electrolytic on VM [ ] 100nF ceramic on VM [ ] 100nF ceramic on VIO FSR front-end x4: [ ] 10k pull-down [ ] 1k series [ ] 100nF 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
POWER: ESP32 powered from 5V_SYS ONLY - never directly from LiPo Charging and actuation MUTUALLY EXCLUSIVE Firmware disables STEPPER_ENN on USB/charge detect LAYOUT (single-layer PCB - jumpers allowed): Zone A (LEFT): LiPo, TP4056, XL6009, bulk caps Zone B (CENTRE): TMC2209, motor output traces Zon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
ENGINEERING NOTES

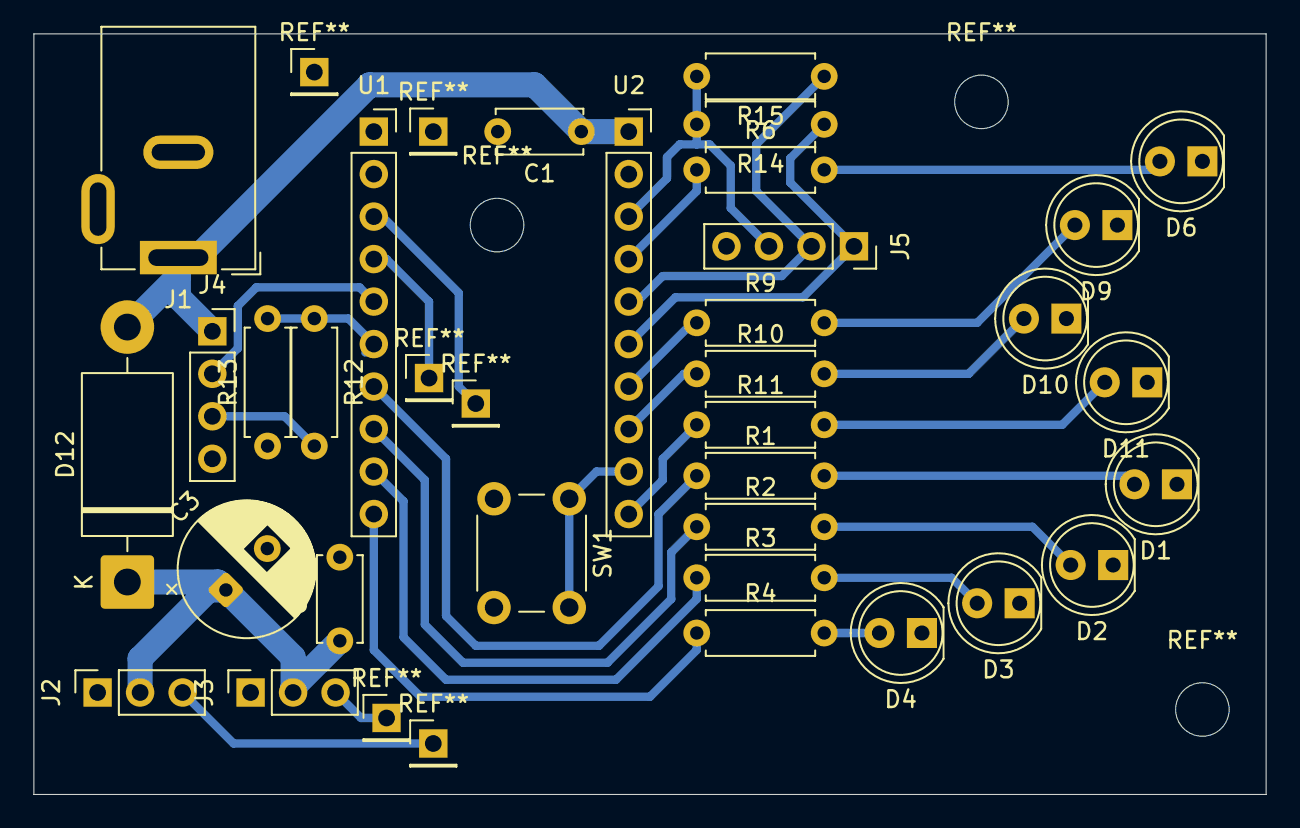
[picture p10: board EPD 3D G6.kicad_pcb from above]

Board: 2 copper layers, 73.7 x 45.5 mm, 32 parts (0 on the bottom side), 28 nets.

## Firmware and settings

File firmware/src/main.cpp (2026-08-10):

//  Affective Core AC-7 — Firmware v3.0
//  Companion Systems Inc.
//
//  Continuous, proximity-driven behaviour (no discrete interaction modes
//  in this revision — that's a deliberate pivot from v2.0's
//  RESTING/CONTACT/COMMAND/OVERLOAD/SHUTDOWN state machine):
//    - Aux LEDs chase top-to-bottom in a wrapping pulse
//    - Servo A sweeps a 90° arc (45°→135°→45°), servo B the full 180°
//      (0→180→0), both continuously and phase-opposite (mirrored)
//    - Ultrasonic proximity continuously scales both speeds — closer
//      object = faster chase and faster sweep
//    - OLED always shows an eye, blinking at random intervals
//
//  Hardware: ESP32-C6-Supermini, 2x SG92R micro servo (5V, continuous sweep),
//  HC-SR04 ultrasonic (proximity → speed), 8x auxiliary "pulse point"
//  LEDs (4 PWM-faded + 4 on/off — LEDC channel budget, see config.h),
//  I2C SSD1306 OLED (always-on eye animation). BLE telemetry (distance +
//  speed multiplier, ~10Hz notify) for the debug dashboard at
//  dashboard/index.html — see ble_telemetry.h/.cpp. Button (BTN_SIG/SW1)
//  is wired on the board but not read by this revision.

#include <Arduino.h>
#include <ESP32Servo.h>
#include <Wire.h>
#include <Adafruit_GFX.h>
#include <Adafruit_SSD1306.h>
#include "config.h"
#include "ble_telemetry.h"

// ─── State ────────────────────────────────────────────────────────────────────

Servo servoA, servoB;
Adafruit_SSD1306 display(OLED_WIDTH, OLED_HEIGHT, &Wire, -1);

float lastDistanceCm      = PROXIMITY_FAR_CM;
unsigned long lastPingAt  = 0;

bool blinking              = false;
unsigned long blinkStartAt = 0;
unsigned long nextBlinkAt  = 0;

// ─── Ultrasonic Ranging ─────────────────────────────────────────────────────────

// Non-blocking-ish single ping. Returns last good reading if polled too soon
// or if the echo timed out (no reflection in range).
static float pingDistanceCm() {
    unsigned long now = millis();
    if (now - lastPingAt < ULTRASONIC_POLL_MS) return lastDistanceCm;
    lastPingAt = now;

    digitalWrite(PIN_TRIG, LOW);
    delayMicroseconds(2);
    digitalWrite(PIN_TRIG, HIGH);
    delayMicroseconds(10);
    digitalWrite(PIN_TRIG, LOW);

    unsigned long durationUs = pulseIn(PIN_ECHO, HIGH, ULTRASONIC_TIMEOUT_US);
    if (durationUs == 0) return lastDistanceCm;   // timeout — keep last value

    lastDistanceCm = (durationUs / 2.0f) / 29.1f;  // speed of sound ≈ 343 m/s
    return lastDistanceCm;
}

// ─── Proximity → Speed ──────────────────────────────────────────────────────────

// 1.0x at/beyond PROXIMITY_FAR_CM, ramps linearly up to SPEED_MULTIPLIER_MAX
// at/below PROXIMITY_NEAR_CM. Applied to both the servo sweep and LED chase.
static float speedMultiplier(float distanceCm) {
    float d = constrain(distanceCm, PROXIMITY_NEAR_CM, PROXIMITY_FAR_CM);
    float t = (PROXIMITY_FAR_CM - d) / (PROXIMITY_FAR_CM - PROXIMITY_NEAR_CM);
    return 1.0f + t * (SPEED_MULTIPLIER_MAX - 1.0f);
}

// ─── Servo Sweep ────────────────────────────────────────────────────────────────

// Continuous triangle-wave sweep. Servo A covers its own, narrower
// SERVO_A_MIN/MAX_ANGLE (90°, mechanically limited); servo B covers the
// full SERVO_MIN_ANGLE..MAX_ANGLE (180°). Both share the same phase,
// mapped inverted into A's range, so they reach their respective
// extremes at the same instant — A at its max exactly when B is at 180°,
// A at its min exactly when B is at 0° — rather than moving in lockstep.
//
// Period shrinks as speedMult grows, but is floored at
// SERVO_SWEEP_MIN_PERIOD_MS so it never asks the servo to reverse before
// it's physically finished traveling the full range (see config.h for
// why — a shorter floor is what causes the "stalls halfway, snaps back"
// look instead of a full sweep).
static void updateServos(float speedMult) {
    uint32_t period = (uint32_t)(SERVO_SWEEP_PERIOD_MS / speedMult);
    if (period < SERVO_SWEEP_MIN_PERIOD_MS) period = SERVO_SWEEP_MIN_PERIOD_MS;

    float phase    = (float)(millis() % period) / (float)period;         // 0..1
    float triangle = (phase < 0.5f) ? (phase * 2.0f) : (2.0f - phase * 2.0f); // 0..1..0

    int angleA = SERVO_A_MAX_ANGLE - (int)(triangle * (SERVO_A_MAX_ANGLE - SERVO_A_MIN_ANGLE));
    int angleB = SERVO_MIN_ANGLE + (int)(triangle * (SERVO_MAX_ANGLE - SERVO_MIN_ANGLE));

    servoA.write(angleA);
    servoB.write(angleB);
}

// ─── LED Chase (top → bottom, wrapping) ─────────────────────────────────────────

// Write one aux LED's brightness — PWM-fade if the channel budget allows
// (PIN_LED_AUX_PWM[index] true), otherwise plain on/off at half-brightness
// threshold. See config.h for why only 4 of 8 channels get real PWM.
static void writeAuxLed(uint8_t index, uint8_t brightness) {
    if (PIN_LED_AUX_PWM[index]) {
        analogWrite(PIN_LED_AUX[index], brightness);
    } else {
        digitalWrite(PIN_LED_AUX[index], brightness >= 128 ? HIGH : LOW);
    }
}

// A glow that sweeps top→bottom through PIN_LED_AUX[] and wraps back to the
// top continuously. Period shrinks with speedMult, same as the servos.
static void updateLedChase(float speedMult) {
    uint32_t period = (uint32_t)(LED_PULSE_PERIOD_MS / speedMult);
    if (period < 150) period = 150;

    float pos = (float)(millis() % period) / (float)period * PIN_LED_AUX_COUNT;

    for (uint8_t i = 0; i < PIN_LED_AUX_COUNT; i++) {
        float d = fabsf((float)i - pos);
        d = min(d, (float)PIN_LED_AUX_COUNT - d);   // wrap distance, shortest way around
        float glow = max(0.0f, 1.0f - d / LED_PULSE_WIDTH);
        writeAuxLed(i, (uint8_t)(255 * glow));
    }
}

// ─── OLED Eye ────────────────────────────────────────────────────────────────────

static void scheduleNextBlink() {
    nextBlinkAt = millis() + random(BLINK_MIN_INTERVAL_MS, BLINK_MAX_INTERVAL_MS);
}

// Always-on eye, blinking at random intervals independent of the chase/sweep.
static void updateEye() {
    unsigned long now = millis();

    if (!blinking && now >= nextBlinkAt) {
        blinking     = true;
        blinkStartAt = now;
    } else if (blinking && now - blinkStartAt > BLINK_DURATION_MS) {
        blinking = false;
        scheduleNextBlink();
    }

    display.clearDisplay();
    int cx = OLED_WIDTH / 2, cy = OLED_HEIGHT / 2;
    int rx = OLED_WIDTH / 3, ry = OLED_HEIGHT / 3;

    if (blinking) {
        // Closed eyelid — a thin horizontal bar across the eye's center line.
        display.fillRoundRect(cx - rx, cy - 2, rx * 2, 4, 2, SSD1306_WHITE);
    } else {
        // Open eye — outer eyeball with a dark pupil punched out of the center.
        display.fillCircle(cx, cy, ry, SSD1306_WHITE);
        display.fillCircle(cx, cy, ry / 2, SSD1306_BLACK);
    }
    display.display();
}

// ─── Setup ────────────────────────────────────────────────────────────────────

void setup() {
    Serial.begin(115200);
    delay(300);
    Serial.println();
    Serial.println(F("━━━━━━━━━━━━━━━━━━━━━━━━━━━━━━━━━━━━━━━━━━━━━━━"));
    Serial.println(F("  AFFECTIVE CORE  Model AC-7  Companion Series"));
    Serial.println(F("  Companion Systems Inc.  |  Firmware v3.0"));
    Serial.println(F("  Synthetic Emotional Verification Organ"));
    Serial.println(F("━━━━━━━━━━━━━━━━━━━━━━━━━━━━━━━━━━━━━━━━━━━━━━━"));

    // Allocate LEDC timers for ESP32Servo (C6 has 4 timers: 0–3)
    ESP32PWM::allocateTimer(0);
    ESP32PWM::allocateTimer(1);
    ESP32PWM::allocateTimer(2);
    ESP32PWM::allocateTimer(3);

    servoA.setPeriodHertz(50);
    servoB.setPeriodHertz(50);
    servoA.attach(PIN_SERVO_A, SERVO_PULSE_MIN, SERVO_PULSE_MAX);
    servoB.attach(PIN_SERVO_B, SERVO_PULSE_MIN, SERVO_PULSE_MAX);
    servoA.write(SERVO_A_MAX_ANGLE);   // matches triangle=0 state in updateServos(), no jump on first loop
    servoB.write(SERVO_MIN_ANGLE);

    // Ultrasonic
    pinMode(PIN_TRIG, OUTPUT);
    pinMode(PIN_ECHO, INPUT);
    digitalWrite(PIN_TRIG, LOW);

    // Button — wired, not read by this firmware revision
    pinMode(PIN_BUTTON, INPUT_PULLUP);

    // Auxiliary LED array
    for (uint8_t i = 0; i < PIN_LED_AUX_COUNT; i++) {
        pinMode(PIN_LED_AUX[i], OUTPUT);
        writeAuxLed(i, 0);
    }

    // I2C OLED
    Wire.begin(PIN_I2C_SDA, PIN_I2C_SCL);
    if (!display.begin(SSD1306_SWITCHCAPVCC, OLED_I2C_ADDRESS)) {
        Serial.println(F("[AC-7] OLED not found at boot — check J5 wiring/address"));
    } else {
        display.clearDisplay();
        display.display();
    }

    // Seed PRNG from hardware entropy
    randomSeed(esp_random());
    scheduleNextBlink();

    lastPingAt = millis();

    // BLE telemetry — for the debug dashboard (dashboard/index.html)
    bleTelemetryBegin();

    Serial.println(F("[AC-7] Emotional display active. Trust calibration nominal."));
}

// ─── Loop ─────────────────────────────────────────────────────────────────────

void loop() {
    float distance  = pingDistanceCm();
    float speedMult = speedMultiplier(distance);

    updateServos(speedMult);
    updateLedChase(speedMult);
    updateEye();
    bleTelemetryUpdate(distance, speedMult);

    static unsigned long lastPrint = 0;
    if (millis() - lastPrint > 2000) {
        lastPrint = millis();
        Serial.printf("[AC-7] dist=%.1fcm  speed=%.2fx\n", distance, speedMult);
    }
}

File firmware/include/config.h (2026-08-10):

#pragma once

// ─── Pin Assignments ── ESP32-C6-Supermini ────────────────────────────────────
// Matches the finalized KiCad schematic exactly — see
// docs/pcb-design-reference.md §4/§5.2 for the full net-by-net mapping.

// Servos — 180° hobby servos, continuous sweep (see SERVO_* below), not a
// cardiac contraction waveform in this firmware revision.
#define PIN_SERVO_A       0
#define PIN_SERVO_B       1

// Ultrasonic distance sensor (HC-SR04) — drives both the LED chase speed
// and servo sweep speed continuously; closer object = faster motion.
// ECHO is 5V logic on the sensor — it MUST be divided down to 3.3V
// before reaching PIN_ECHO (R12/R13 on the PCB).
#define PIN_TRIG          2
#define PIN_ECHO          3

// Momentary button — wired on the board (BTN_SIG/SW1, GP9/BOOT strap)
// but not read by this firmware revision. Reserved for a future mode.
#define PIN_BUTTON        9

// I2C OLED (SSD1306 128x64 or similar) — always-on random eye-blink
// animation, independent of the LED chase / servo sweep.
#define PIN_I2C_SDA       18
#define PIN_I2C_SCL       19
#define OLED_WIDTH        128
#define OLED_HEIGHT       64
#define OLED_I2C_ADDRESS  0x3C

// Auxiliary "pulse point" LEDs, listed in PHYSICAL TOP-TO-BOTTOM ORDER on
// the shell — this is what makes the chase animation sweep in one
// direction. Matches the schematic's D1/D6/D9/D10/D11 designators;
// GP10/GP12 (former LED5) and GP19/GP18 (former LED7/LED8, now the I2C
// bus) are not part of this board's LED array — see PCB doc §4 for why
// the LED numbering has gaps.
//
// Do not reorder this array without updating the physical LED placement
// on the shell to match — see docs/pcb-design-reference.md §7.1.
#define PIN_LED_AUX_COUNT 8
static const uint8_t PIN_LED_AUX[PIN_LED_AUX_COUNT] =
    { 20, 15, 14, 8, 4, 5, 6, 7 };
    // LED6   LED9  LED10 LED11 LED1 LED2 LED3 LED4

// Which of the above are PWM-capable (fade) vs on/off only. The C6 has
// only 6 total LEDC channels — the 2 servos use 2, leaving 4 free — so
// only 4 of these 8 LEDs can fade; the rest are driven as plain on/off
// (see writeAuxLed() in main.cpp). Must stay index-aligned with
// PIN_LED_AUX[] above.
static const bool PIN_LED_AUX_PWM[PIN_LED_AUX_COUNT] =
    { false, false, false, false, true, true, true, true };

// ─── Servo Sweep ───────────────────────────────────────────────────────────────
// Servo A is mechanically limited to a 90° arc, so it gets its own
// (narrower) range. Servo B sweeps the full 180°. Both share the same
// timing/phase (see updateServos() in main.cpp), so they still reach
// their respective extremes at the same instant: A at its max (90°)
// exactly when B is at 180°, A at its min (0°) exactly when B is at 0°.
#define SERVO_A_MIN_ANGLE      0
#define SERVO_A_MAX_ANGLE      90
#define SERVO_MIN_ANGLE        0
#define SERVO_MAX_ANGLE        180
#define SERVO_PULSE_MIN        500     // µs, standard 500–2400 range
#define SERVO_PULSE_MAX        2400
#define SERVO_SWEEP_PERIOD_MS  4800    // time for one full 0→180→0 cycle, at rest (0.5x speed)

// Hard floor on how short the sweep period is allowed to get, regardless
// of proximity speed-up. An SG92R takes roughly 0.35-0.4s to travel a
// full 180° one-way under light load — a period shorter than ~750ms
// commands the servo to reverse direction before it has physically
// finished traveling, which looks like it "stalls halfway and snaps
// back" rather than completing its full range of motion.
#define SERVO_SWEEP_MIN_PERIOD_MS  750

// ─── LED Chase (top → bottom, wrapping) ─────────────────────────────────────────
#define LED_PULSE_PERIOD_MS    1600    // time for the glow to sweep the full chain, at rest
#define LED_PULSE_WIDTH        2.2f    // glow falloff width, in LED-index units

// ─── Proximity → Speed Mapping ──────────────────────────────────────────────────
// Distance is continuously mapped to a speed multiplier applied to both
// the servo sweep and the LED chase — no discrete interaction modes in
// this firmware revision.
#define PROXIMITY_NEAR_CM      5.0f    // multiplier maxes out at/below this distance
#define PROXIMITY_FAR_CM       60.0f   // multiplier is 1.0x at/beyond this distance
#define SPEED_MULTIPLIER_MAX   5.0f    // how much faster than resting, at closest range
#define ULTRASONIC_TIMEOUT_US  25000UL // ~4.3 m max range, avoids blocking pulseIn()
#define ULTRASONIC_POLL_MS     60      // minimum interval between pings

// ─── OLED Eye Blink ──────────────────────────────────────────────────────────────
#define BLINK_DURATION_MS      140     // how long the eye stays closed per blink
#define BLINK_MIN_INTERVAL_MS  1500    // shortest gap between blinks
#define BLINK_MAX_INTERVAL_MS  6000    // longest gap between blinks

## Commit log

2026-08-06 Initial commit: Proof of Feeling — Affective Core AC-7
    [EPD 3D G6.kicad_pcb, EPD 3D G6.kicad_sch]
2026-08-08 add photos
    [EPD 3D G6.kicad_pcb, PoF PCB.step]
2026-08-09 added print files
    [EPD 3D G6.kicad_pcb, EPD 3D G6.kicad_sch, PoF PCB.step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]
